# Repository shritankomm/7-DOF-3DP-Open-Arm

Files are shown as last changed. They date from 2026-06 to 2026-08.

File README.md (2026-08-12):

# 7-DOF Open Source 3D Printed Humanoid Arms

An open-source, fully 3D-printable 7-DOF pair of humanoid robotic arms designed as an accessible research platform. Built with high-torque Feetech serial bus servos and a Raspberry Pi 4, it supports ROS2 for motion planning/simulation, VR teleoperation for intuitive control, and autonomous/agentic operation via an onboard camera. With all CAD files, BOM, and software fully open source, anyone can build and expand on it for under $800.



---

## Inspiration
- I made this project because I find interest in is human-related robotics. The idea of being able to create some kind of device that can help or mimic a human's movement is a very cool thing, as human mechanics are very intricate. That's why I took the time to create as accurate a replica of the humans arms to make it work as well as possible. In the past, I have made foot prosthetics and other medical device prototypes, and this felt like a great next step. I also made this as an act to make a low-cost research tool for people to use, and as an ability for others and me to begin learning more advanced robotics. I'm exploring ROS, OpenCV, and other things that can be integrated with this project, and I feel this is the best way for people to learn things like this. I will document this journey and open-source it so others can follow and build upon the project, doing bigger, better, and more impressive things than I am with this project. I aim to inspire people to do more human-centered robotics, as it is the future. I have plans for more humanoid robot projects (a pair of legs, for example) and will document them on GitHub and make them open source so everyone can learn and grow as engineers.

---

## Features of the Project

- 7 Degrees of Freedom - full human-like range of motion across the shoulder, elbow, and wrist
- High-torque serial bus servos - 30 kgcm at most joints, 50kgcm at the shoulder
- Fully 3D printable - all structural components printed in PETG at high infill, no custom machined parts required
- ROS2 integration - built for compatibility with the broader robotics software ecosystem
- Advanced simulation using Gazebo 
- VR teleoperation - control the arm intuitively through a VR headset
- Autonomous and agentic control - onboard Raspberry Pi 4 and camera enable independent perception and decision-making
- Under $800 - accessible to students, researchers, and makers without big budgets

---

## Hardware

# Bill of Materials

| # | Part Name | Link | Source | Qty | Unit Price | Extended Price | Notes | Where It's Needed |
|---|---|---|---|-----|---|---|---|---|
| 1 | 1 KG PETG filament roll | [Link](https://www.amazon.com/gp/product/B0DJS3PJVX) | Amazon | 2 | $15.00 | $30.00 | | Needed to print out all the parts |
| 2 | STS3215 Servo (12V 30KG) | [Link](https://www.amazon.com/gp/product/B0FLPQQ4FR) | Amazon | 14 | $24.00 | $336.00 | | Main actuators used at all joints except the top shoulder roll joint |
| 3 | Serial Bus Servo Driver Board | [Link](https://www.amazon.com/gp/product/B0DK79JNNK) | Amazon | 2 | $11.00 | $22.00 | | Servo driver, supplies power to the arm and connects the Pi to send movement commands to the servos |
| 4 | Raspberry Pi 4 | [Link](https://www.amazon.com/gp/product/B0CK2FCG1K) | Amazon | 1 | $100.00 | $100.00 | | Microcontroller of the build, runs ROS and other programs |
| 5 | 12V 10A power supply | [Link](https://www.amazon.com/gp/product/B07MXXXBV8) | Amazon | 1 | $23.00 | $23.00 | | Connects to the wall and supplies power to the build |
| 6 | M3 heat set inserts | [Link](https://www.amazon.com/gp/product/B0DMNWZ15X) | Amazon | 1 | $7.00 | $7.00 | Kit includes both screws and inserts; same price if bought separately | Inserts go into 3D prints to strengthen threads; screws fasten components together |
| 7 | Logitech C270 Webcam | [Link](https://www.amazon.com/gp/product/B004FHO5Y6) | Amazon | 1 | $18.00 | $18.00 | For vision | USB cam for vision capabilities, lets the Pi make decisions based on vision |
| 8 | 4040 extrusion, 800mm | [Link](https://www.amazon.com/dp/B09WCSX8H3) | Amazon | 1 | $27.00 | $27.00 | | Extrusion bar needed to keep the arms elevated, acts as middle support |
| 9 | STS3250M | [Link](https://www.aliexpress.us/item/3256811842648895.html) | AliExpress | 2 | $75.00 | $150.00 | For the shoulder roll DOF (doesn't account for tariffs) | Servos for the shoulder pitch joints, higher torque |
| 10 | 2x4, 60 inches | [Link](https://www.homedepot.com/p/ProWood-2-in-x-4-in-x-4-ft-2-Grade-Dimensional-Lumber-271736/300524962) | Home Depot | 1 | $5.00 | $5.00 | For the stand | For the stand |
| 11 | 3" wood screws | [Link](https://www.amazon.com/Wensilon-Screws-137pcs-lbs-Exterior-Resistant/dp/B0FCFFN4LB) | Amazon | 8 | $6.00 | $6.00 | For the stand | For the stand |

**Total (excluding shipping): $700.00**

Link to BOM Spreadsheet - https://docs.google.com/spreadsheets/d/1n2eNZaHsdRUR-5rRqqR8Au6a7Qyu3wT80XMrWUhEQkk/edit?usp=sharing

---

## Electrical

This is the preliminary wiring diagram for the project.



## Repository Structure

- CAD/          - CAD files (STL/STEP/Onshape Public Link), screenshots, Parts List, 3d print settings 
- software/     - Software + electrical diagram, firmware, and ROS2 control code
- docs/      - Build journal entries and progress updates/documentation
- BOM.md        - Full bill of materials with links and prices
- instructions.md - Build and assembly instructions 
- pictures.md - pictures of the fully assembled arm 
- README.md     - This file

---

## Build Instructions

Full step-by-step assembly instructions can be found in instructions.md. Follow along via the build journal in /DOCS to track design decisions and progress in the meantime. (coming soon)

---

## License
Hardware designs: CERN-OHL-S v2 (or CC BY 4.0)

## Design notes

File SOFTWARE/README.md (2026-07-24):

# Humanoid Arms — ROS 2 Control & Simulation Software

A **ROS 2 (Jazzy)** software stack for an open-source **7-DOF humanoid
arms**: robot description (URDF/meshes), MoveIt motion planning, RViz/Gazebo
simulation, and a set of Python tools for **kinesthetic capture, replay, hardware
control, and real-time bilateral teleoperation** of the physical arm.

This folder is a self-contained **ROS 2 workspace** built with `colcon` — it holds
two ROS 2 packages (`humanoid_arms` and `humanoid_arms_moveit_config`, each with a
standard `package.xml`). Clone it, build it, and run.

**CHECK FILE_TREE.md TO SEE WHERE FILES ARE
**
---

## Requirements

- **Ubuntu 24.04**
- **ROS 2 Jazzy**
- **Gazebo Harmonic** (for the physics sim; optional if you only want RViz + MoveIt)
- **Python 3** with the **Feetech servo SDK** (`scservo_sdk`) for any hardware scripts

---

## Packages

| Package | What it is |
|---|---|
| `humanoid_arms` | Robot description (URDF + STL meshes), Gazebo launch, and all hardware/teleop Python scripts (`scripts/`). |
| `humanoid_arms_moveit_config` | MoveIt configuration (SRDF, kinematics, OMPL, controllers, joint limits) and the `demo.launch.py` that brings up RViz + MoveIt with mock controllers. |

> **Two URDFs, by design.** Gazebo uses `humanoid_arms/urdf/humanoid_arms_final.urdf`
> (with the Gazebo control plugin); MoveIt uses
> `humanoid_arms_moveit_config/config/humanoid_arms.urdf` (with the mock-components
> plugin). They describe the same robot but carry different `<plugin>` blocks.

---

## Build

```bash
# from the workspace root (this folder)
rosdep install --from-paths src -y --ignore-src     # install ROS dependencies
colcon build
source install/setup.bash
```

The Feetech SDK is a **pip** package, not a ROS one, so install it separately:

```bash
pip install feetech-servo-sdk        # provides `scservo_sdk`
```

---

## Wayland workaround (important for GUIs)

On Wayland, RViz and Gazebo can crash or render black. Export these **before any
GUI launch** (put them in your shell profile or prefix each launch):

```bash
export QT_QPA_PLATFORM=xcb
export LIBGL_ALWAYS_SOFTWARE=true
```

---

## Run the simulation

```bash
ros2 launch humanoid_arms_moveit_config demo.launch.py
```

This brings up RViz with the MoveIt MotionPlanning panel. Use **Plan & Execute**
(you must Execute, not just Plan) to pose the arm. The transparent/ghost arm is the
real robot state; the solid arm is the planning goal.

---

## Capture & replay (simulation)

Pose the arm in RViz, then:

```bash
# in the scripts/ directory, with the sim running
python3 capture_keyframes.py left        # ENTER snapshots each pose; s save, q quit
python3 replay_keyframes.py FILE.json --dt 1.5
```

---

## Hardware bring-up

The physical arm uses **Feetech STS3215/STS3250** servos on a TTL bus via a
Waveshare adapter (default `/dev/ttyACM0` @ 1 Mbaud) with a separate 12 V supply.

**Serial port permissions:** add your user to the `dialout` group once
(`sudo usermod -aG dialout $USER`, then log out/in), or per-session
`sudo chmod a+rw /dev/ttyACM0`.

### 1. Assign servo IDs
Left arm = IDs 2–8, left claw = 9, right arm = 10–16, right claw = 17.
```bash
python3 assign_ids_right_and_claws.py    # one fresh (ID 1) servo at a time
python3 ping_all_ids.py                  # confirm 2–17 respond
```

### 2. Calibrate
`servo_calibration.json` and `mirror_calibration.json` **in this repo are the
author's calibration** for a specific physical arm. **You must recalibrate for your
own hardware** — the zero ticks and signs will not match your build.

```bash
python3 capture_zero.py        # record each joint's zero tick (arm at zero pose)
python3 sign_calibrate.py      # find each joint's sign
python3 rezero_servo.py <id>   # re-center a servo to mid-range (fixes tick wraparound)
```

### 3. Drive the arm from captured motion
```bash
python3 replay_hardware.py FILE.json     # keyframes -> servo ticks
python3 teleop_record.py                 # go limp, record motion by hand (50 Hz)
python3 teleop_replay.py FILE.json       # stream a recording back onto the servos
```

---

## Real-time bilateral teleoperation

Move the **left** arm by hand (limp) and the **right** arm mirrors it live.

```bash
# 1. discover the reference pose + per-joint mirror signs (one time, watch the arm)
python3 mirror_calibrate.py              # writes mirror_calibration.json (8 pairs)

# 2. real-time mirror
python3 teleop_mirror.py                 # left limp -> right follows, incl. grippers
```

Just the grippers, in isolation:
```bash
python3 gripper_mirror.py
```

**How the mirror works.** Both arms use identical direct-drive servos, so mirroring
is done in raw tick space: `R = R0 + sign*(L - L0)`. `L0/R0` are the ticks at a
shared reference pose; `sign` (±1) encodes which joints are physically mirrored and
is found empirically during calibration. The teleop unwraps the 0–4095 tick seam so
yaw joints don't fling a full turn, and applies EMA smoothing + a per-loop slew
limit for safety.

---

## Script reference

All scripts live in `src/humanoid_arms/scripts/`. Sim scripts need `demo.launch.py`
running; hardware scripts need the servo bus powered and readable on `/dev/ttyACM0`.

**Servo bus setup**
| Script | What it does |
|---|---|
| `assign_servo_ids.py` | Assign IDs 2–8 to fresh servos (left arm), one at a time. |
| `assign_ids_right_and_claws.py` | Assign IDs 9–17 (left claw, right arm, right claw). |
| `ping_all_ids.py` | Ping the expected IDs and report which servos respond. |
| `map_servos.py` | Wiggle each servo to discover which one drives which joint. |

**Calibration**
| Script | What it does |
|---|---|
| `capture_zero.py` | Read-only: record each joint's zero tick with the arm at its URDF-zero pose. |
| `sign_calibrate.py` | Sim-vs-hardware jog to find each joint's ±1 sign. |
| `rezero_servo.py <id>` | Re-center any servo to mid-range and auto-update the calibration files (fixes tick-wraparound). |
| `rezero_elbow.py` | Elbow-only re-center — **superseded by `rezero_servo.py 5`** (kept for reference). |
| `read_live.py <id>` | Torque-off live tick readout — move a joint by hand and watch its ticks. |

**Simulation / IK**
| Script | What it does |
|---|---|
| `ik_trajectory.py` | FK-anchored straight-line Cartesian sweep; solves IK per waypoint, writes a CSV. |
| `ik_explorer.py` | Builds RobotModel from URDF+SRDF; solves single-point and straight-line Cartesian IK offline. |
| `pose_and_capture.py` | Interactive-marker poser + capture — **superseded** by MoveIt Plan&Execute + `capture_keyframes.py`. |

**Keyframe capture & replay**
| Script | What it does |
|---|---|
| `capture_keyframes.py` | Snapshot the current joint states as keyframes (sim). |
| `replay_keyframes.py` | Replay a keyframe JSON through the controllers (sim). |
| `replay_hardware.py` | Replay a keyframe JSON on the physical servos (rad→tick). |
| `hw_goto.py` | Drive the real arm to one pose/keyframe and optionally mirror it in the sim, to validate calibration. |

**Kinesthetic teleop (record by hand → replay)**
| Script | What it does |
|---|---|
| `teleop_record.py` | Go limp, record dense motion (50 Hz) as you move the arm by hand. |
| `teleop_replay.py` | Stream a teleop recording back onto the servos. |

**Real-time bilateral (mirror) teleop**
| Script | What it does |
|---|---|
| `mirror_calibrate.py` | Discover the reference pose + per-joint mirror signs → writes `mirror_calibration.json`. |
| `teleop_mirror.py` | Real-time: left arm limp leads, right arm mirrors it (all 7 joints + gripper). |
| `gripper_mirror.py` | Standalone gripper-only mirror (left claw → right claw). |

**Basic bring-up tests**
| Script | What it does |
|---|---|
| `test_wiggle.py` | Gently wiggle a single servo around its current position. |
| `test_wiggle_dual.py` | Sync-wiggle two servos at once (group sync-write demo). |

---

## Safety notes

- **Read servo positions before enabling torque** so the arm doesn't snap to a stale
  command.
- Generated IK angles can exceed a servo's physical range — sanity-check before
  driving hardware. The scripts clamp to each joint's `[tick_min, tick_max]`.
- The arm goes **limp** when torque is released (kinesthetic capture, teleop leader) —
  support it so it doesn't fall.
- Confirm the servo bus responds (`ping_all_ids.py`) with 12 V on *before* recording;
  a powered-off bus silently logs frozen fallback values.



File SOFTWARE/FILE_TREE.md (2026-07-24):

# File Tree — `SOFTWARE/`

A guide to what's in this folder and where to find things. 

```
SOFTWARE/
├── README.md                     # start here: requirements, build, run, script reference
├── .gitignore                    # keeps build/ install/ log/, caches, recordings out of git
└── src/                          # colcon looks here for ROS 2 packages
    │
    ├── humanoid_arms/                     # robot description + all Python tooling
    │   ├── package.xml                    # ROS 2 package manifest (name, deps, license)
    │   ├── CMakeLists.txt                 # build/install rules
    │   │
    │   ├── config/
    │   │   └── controllers.yaml           # ros2_control controller definitions
    │   │
    │   ├── launch/
    │   │   ├── display.launch.py          # robot in RViz (no physics)
    │   │   └── gazebo.launch.py           # robot in Gazebo (physics sim)
    │   │
    │   ├── urdf/                          # robot geometry/kinematics description
    │   │   ├── humanoid_arms_final.urdf   # ★ the Gazebo robot model (source of truth)
    │   │   ├── humanoid_arms_collision.urdf     # variant w/ collision geometry
    │   │   ├── humanoid_arms_fixed.urdf         # intermediate build step
    │   │   ├── humanoid_arms_ros2_control.urdf  # intermediate build step
    │   │   ├── add_gazebo_plugin.py       # URDF build helper: injects the Gazebo plugin
    │   │   ├── add_ros2_control.py        # URDF build helper: injects ros2_control block
    │   │   └── add_collisions.py          # URDF build helper: adds collision meshes
    │   │
    │   ├── meshes/                        # 56 .stl CAD meshes the URDF references
    │   │                                  #   (chest_plate, shoulder/elbow/wrist parts,
    │   │                                  #    servo bodies, claw arms, frame extrusions)
    │   │
    │   └── scripts/                       # Python tools (see README "Script reference")
    │       │  ── servo bus setup ──
    │       ├── assign_servo_ids.py        # assign IDs 2–8 (left arm)
    │       ├── assign_ids_right_and_claws.py  # assign IDs 9–17 (claws + right arm)
    │       ├── ping_all_ids.py            # check which servos respond
    │       ├── map_servos.py              # discover which servo drives which joint
    │       │  ── calibration ──
    │       ├── capture_zero.py            # record each joint's zero tick (read-only)
    │       ├── sign_calibrate.py          # find each joint's ±1 sign
    │       ├── rezero_servo.py            # re-center a servo to mid-range (fixes wraparound)
    │       ├── rezero_elbow.py            # elbow-only re-center (superseded by rezero_servo)
    │       ├── read_live.py               # live tick readout, joint moved by hand
    │       ├── servo_calibration.json     # ⚙ per-joint hw calibration (RECALIBRATE for your arm)
    │       ├── mirror_calibration.json    # ⚙ left↔right mirror reference + signs
    │       │  ── simulation / IK ──
    │       ├── ik_trajectory.py           # straight-line Cartesian IK sweep → CSV
    │       ├── ik_explorer.py             # offline IK from URDF+SRDF
    │       ├── pose_and_capture.py        # marker poser (superseded by MoveIt + capture)
    │       │  ── keyframe capture / replay ──
    │       ├── capture_keyframes.py       # snapshot joint poses as keyframes (sim)
    │       ├── replay_keyframes.py        # replay keyframes through controllers (sim)
    │       ├── replay_hardware.py         # replay keyframes on the real servos
    │       ├── hw_goto.py                 # drive real arm to one pose; validate calibration
    │       │  ── kinesthetic teleop ──
    │       ├── teleop_record.py           # go limp, record motion by hand at 50 Hz
    │       ├── teleop_replay.py           # stream a recording back onto the servos
    │       │  ── real-time bilateral (mirror) teleop ──
    │       ├── mirror_calibrate.py        # find reference + mirror signs → mirror_calibration.json
    │       ├── teleop_mirror.py           # ★ left arm limp → right arm mirrors live (+ gripper)
    │       ├── gripper_mirror.py          # standalone gripper-only mirror
    │       │  ── basic bring-up tests ──
    │       ├── test_wiggle.py             # wiggle one servo around its current position
    │       └── test_wiggle_dual.py        # sync-wiggle two servos at once
    │
    └── humanoid_arms_moveit_config/       # MoveIt motion-planning configuration
        ├── package.xml                    # ROS 2 package manifest
        ├── CMakeLists.txt                 # build/install rules
        ├── .setup_assistant               # lets MoveIt Setup Assistant re-open/regenerate this
        │
        ├── config/
        │   ├── humanoid_arms.urdf         # robot model MoveIt uses (mock-controllers variant)
        │   ├── humanoid_arms.srdf         # semantic model: groups, tips, disabled collisions
        │   ├── kinematics.yaml            # IK solver (pick_ik) settings per arm
        │   ├── joint_limits.yaml          # velocity/acceleration limits
        │   ├── ompl_planning.yaml         # OMPL planner config
        │   ├── moveit_controllers.yaml    # maps MoveIt to the ros2_control controllers
        │   ├── ros2_controllers.yaml      # controller manager + controller definitions
        │   ├── pilz_cartesian_limits.yaml # Pilz planner limits
        │   └── moveit.rviz                # saved RViz layout (MotionPlanning panel)
        │
        └── launch/
            ├── demo.launch.py             # ★ full bring-up: MoveIt + RViz + mock controllers
            ├── move_group.launch.py       # the MoveIt planning node
            ├── moveit_rviz.launch.py      # RViz with the MotionPlanning plugin
            ├── rsp.launch.py              # robot_state_publisher
            ├── spawn_controllers.launch.py     # start the ros2_control controllers
            ├── static_virtual_joint_tfs.launch.py  # world→base static TF
            ├── setup_assistant.launch.py  # re-open the MoveIt Setup Assistant
            └── warehouse_db.launch.py     # (optional) motion warehouse database
```

## Where do I go for guide
- **Just run the sim** → `README.md` → *Run the simulation* (`demo.launch.py`)
- **Understand the robot** → `src/humanoid_arms/urdf/humanoid_arms_final.urdf` + `meshes/`
- **Capture & replay a pose** → `scripts/capture_keyframes.py`, `scripts/replay_keyframes.py`
- **Drive the real arm** → `README.md` → *Hardware bring-up* + `scripts/` (assign IDs → calibrate → replay)
- **Bilateral teleop** → `scripts/mirror_calibrate.py` then `scripts/teleop_mirror.py`

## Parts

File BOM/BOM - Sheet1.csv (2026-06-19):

## | Part Name | Link | Quantity | Unit Price | Extended Price | Notes | where it is needed
1 | 1 KG PETG filament roll | link | 2 | $15.00 | $30.00 |  | Needed to print out all the parts
2 | STS3215 Servo (12V 30KG) | link | 14 | $24.00 | $336.00 |  | the main actuators that will be used at all joints except for the top shoulder roll joint
3 | Serial Bus Servo Driver Board | link | 2 | $11.00 | $22.00 |  | the servo driver, will be where power is supplied to the arm and where the Pi is connected to give movement commands to the servos
4 | Rasberry Pi 4 | link | 1 | $100.00 | $100.00 |  | the microcontroller of the build will be used to run ROS and run programs on the build
5 | 12V 10A power supply | link | 1 | $23.00 | $23.00 |  | power supply that will connect to the wall and be used to supply power to the build
6 | m3 heat set inserts | link | 1 | $7.00 | $7.00 | this kit has both screws and inserts but if you were to buy them seperatly it would be the same price | the choice of heatset inserts, which go into the 3d prints to strengthen the threads, and the screws which will be used to fasten components together
7 | Logitech C270 Webcam | link | 1 | $18.00 | $18.00 | for vision | usb cam used for vision capabilities for the project, allows the rasberry pi to make decisions based on vision
8 | 4040 Corner brackets + Tnuts | link | 1 | $20.00 | $20.00 |  | the main piece at the bottom of the extrusion which will bolt to the table and hold the arm in place
9 | 4040 extrusion 800mm | link | 1 | $27.00 | $27.00 |  | the extrusion bar needed to keep the arms in the air, act as. middle support
10 | STSS3250M (doesnt account for the tarrifs) | link | 2 | $75.00 | $150.00 | for the shoulder roll DOF (doesnt account for the tarrifs) | the servos needed for the shoulder pitch joints, higher torque
11 | 5264 connector 3 pin extended wires | link | 1 | $7.00 | $7.00 |  | wire extensions for the motors to allow for proper daisy chaining with the motors so they can all be connected in an open loop.
12 |  |  |  |  | $0.00
 |  |  | ` |  | $740.00 | total

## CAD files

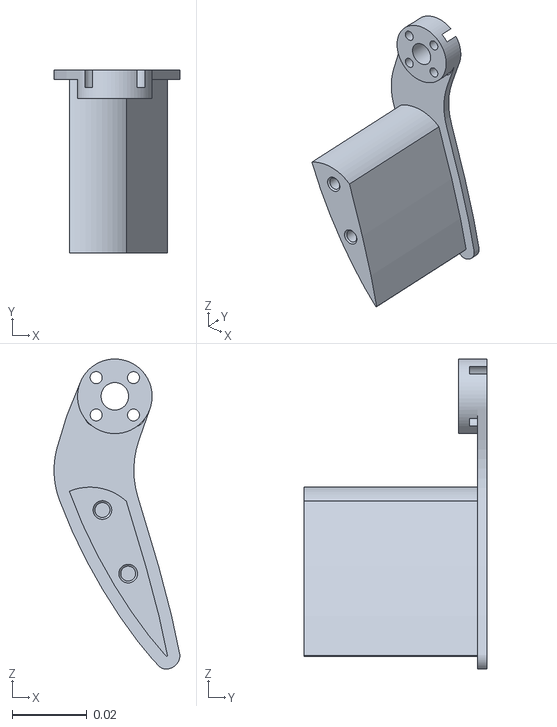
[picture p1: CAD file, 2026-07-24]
SOFTWARE/src/humanoid_arms/meshes/bottom_stationary_claw_arm.stl
0.0337 x 0.0491 x 0.0831

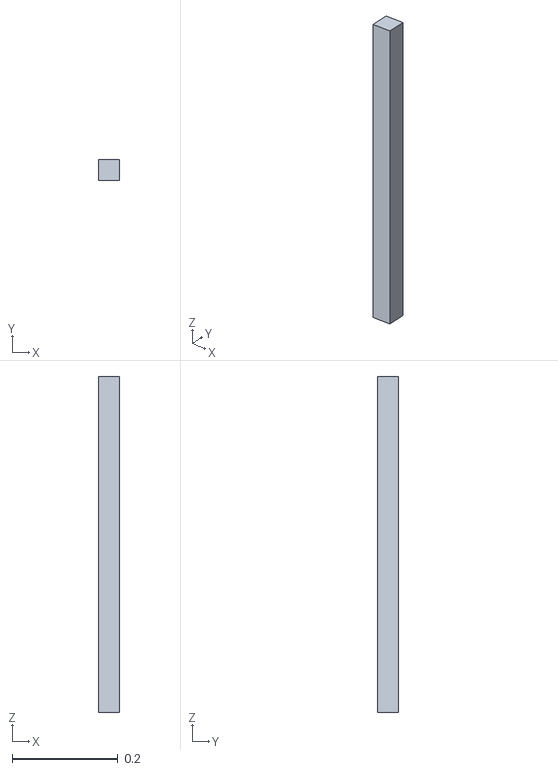
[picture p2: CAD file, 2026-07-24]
SOFTWARE/src/humanoid_arms/meshes/_4040_extrusion.stl
0.04 x 0.04 x 0.635

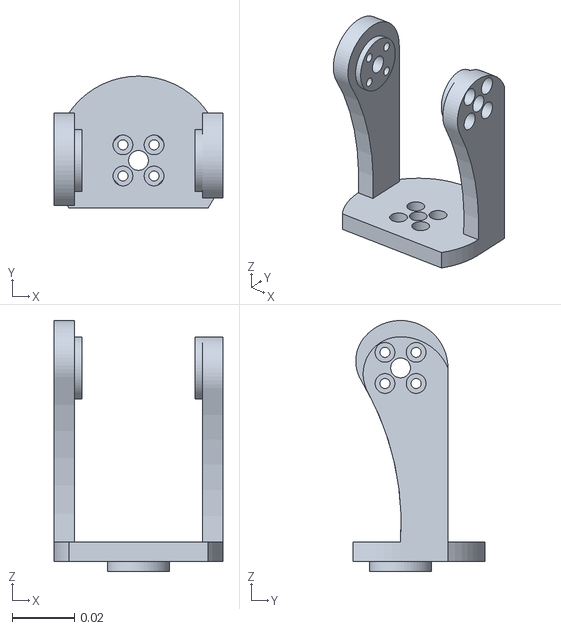
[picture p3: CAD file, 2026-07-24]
SOFTWARE/src/humanoid_arms/meshes/Part_42.stl
0.0542 x 0.0423 x 0.0806

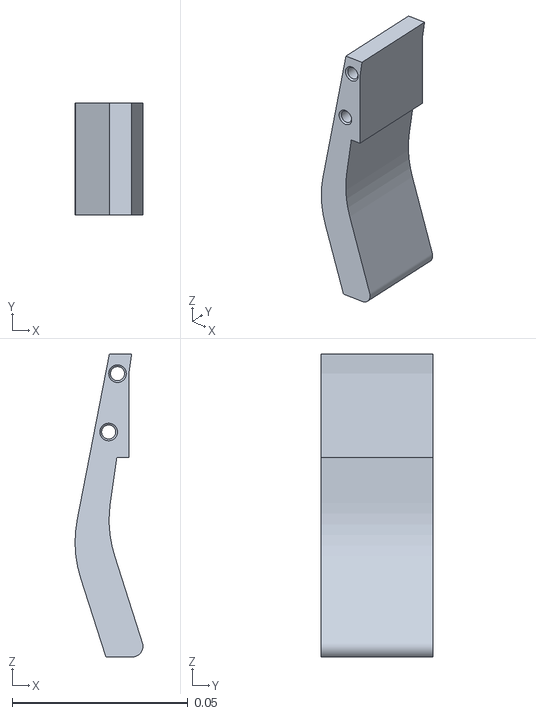
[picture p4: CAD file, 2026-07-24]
SOFTWARE/src/humanoid_arms/meshes/Part_54.stl
0.0193 x 0.0318 x 0.0863

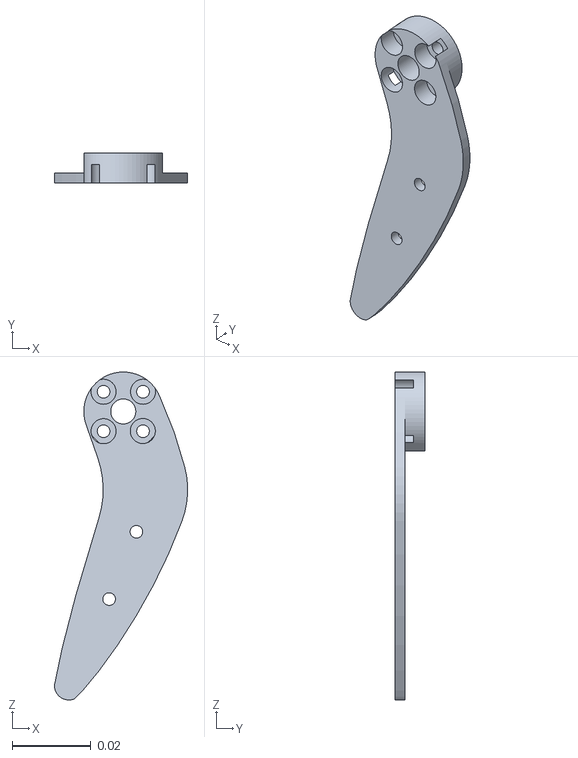
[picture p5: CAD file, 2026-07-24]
SOFTWARE/src/humanoid_arms/meshes/Part_53.stl
0.0337 x 0.00762 x 0.0831

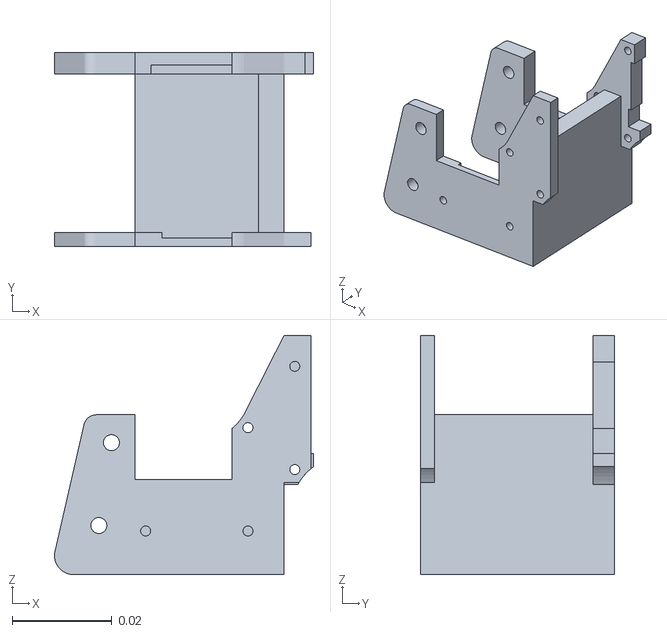
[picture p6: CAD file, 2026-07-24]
SOFTWARE/src/humanoid_arms/meshes/Part_51.stl
0.0519 x 0.0389 x 0.0479

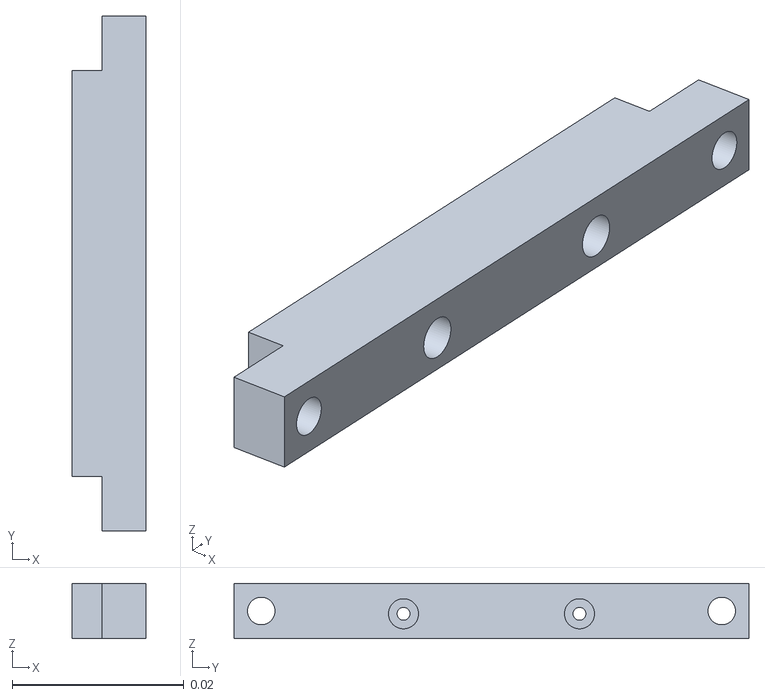
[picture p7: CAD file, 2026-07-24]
SOFTWARE/src/humanoid_arms/meshes/shoulder_pitch_motor_back_plate.stl
0.00858 x 0.06 x 0.00645

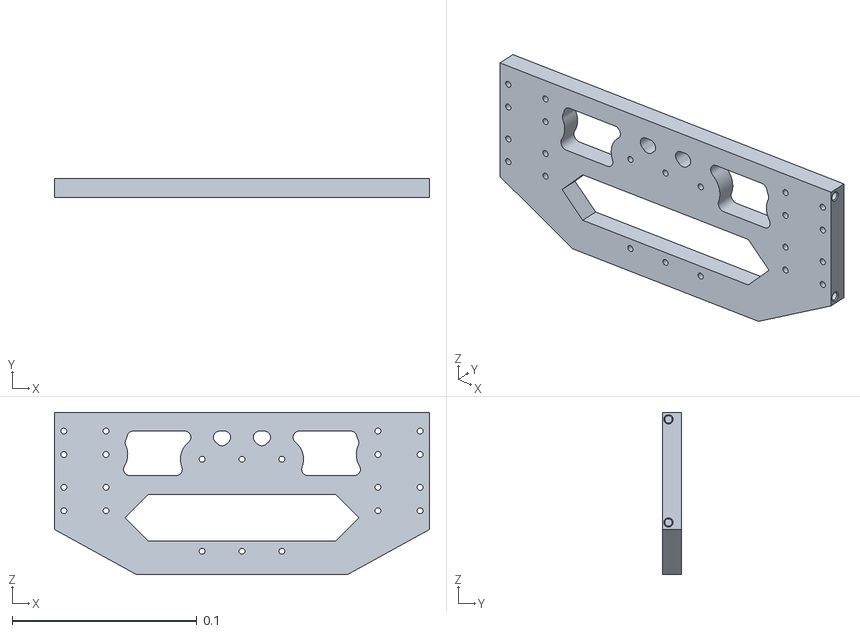
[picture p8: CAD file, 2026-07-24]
SOFTWARE/src/humanoid_arms/meshes/chest_plate_1.stl
0.203 x 0.0102 x 0.088

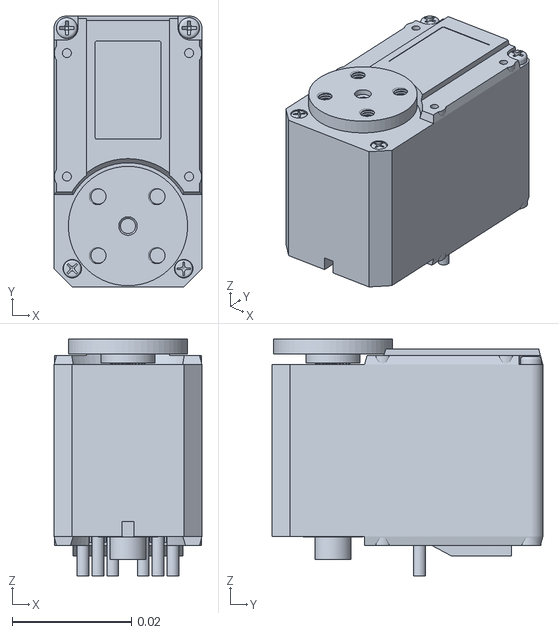
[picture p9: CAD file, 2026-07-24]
SOFTWARE/src/humanoid_arms/meshes/Composant3_3.stl
0.0248 x 0.0454 x 0.0397

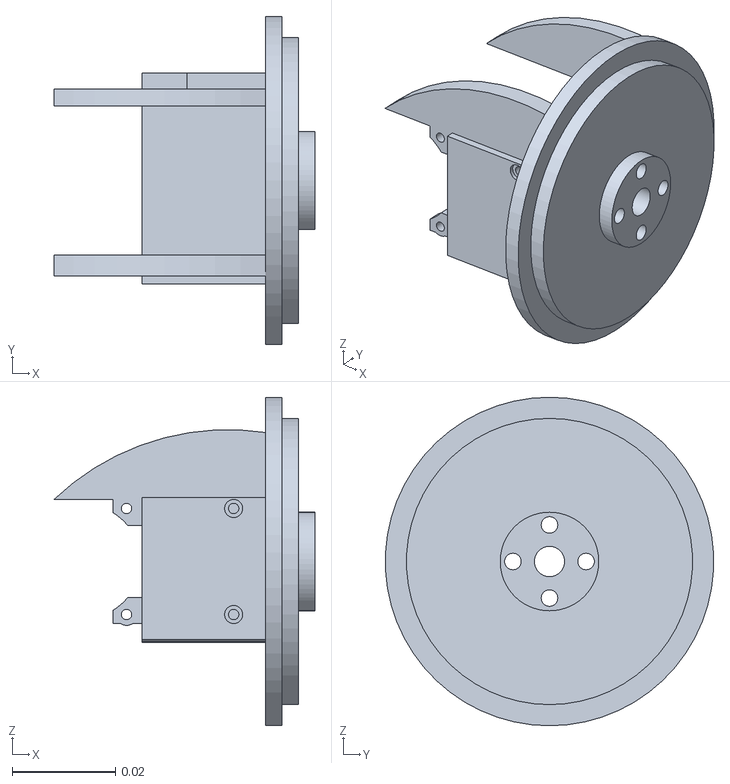
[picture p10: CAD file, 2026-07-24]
SOFTWARE/src/humanoid_arms/meshes/shoulder_motor_holder.stl
0.0505 x 0.0634 x 0.0635

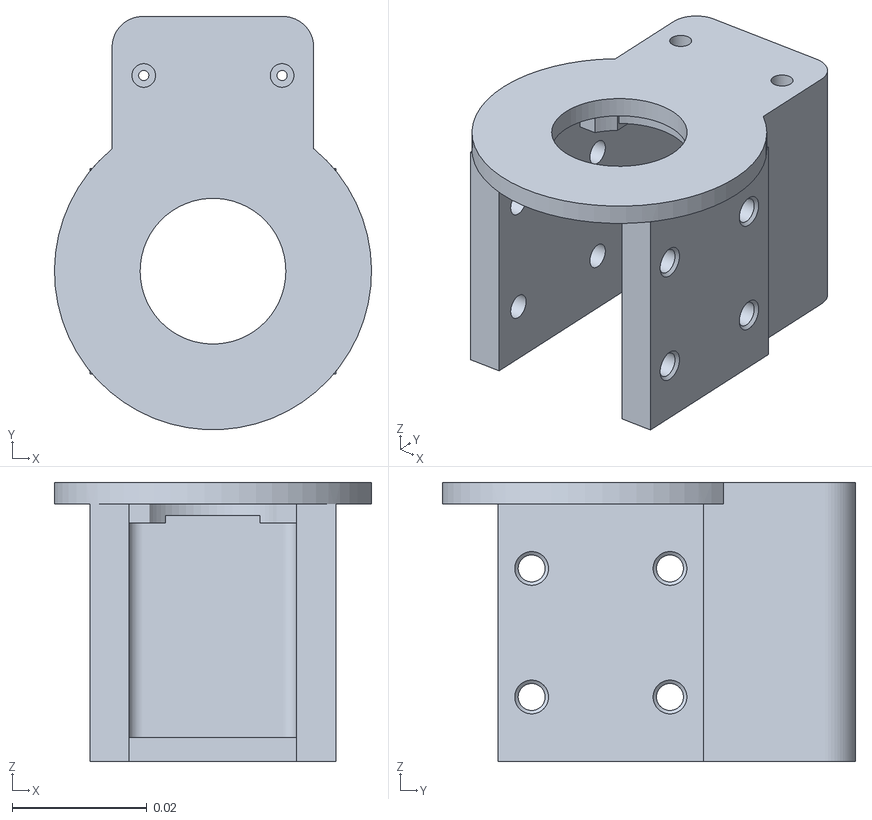
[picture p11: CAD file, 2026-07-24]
SOFTWARE/src/humanoid_arms/meshes/Part_43.stl
0.047 x 0.0612 x 0.0414

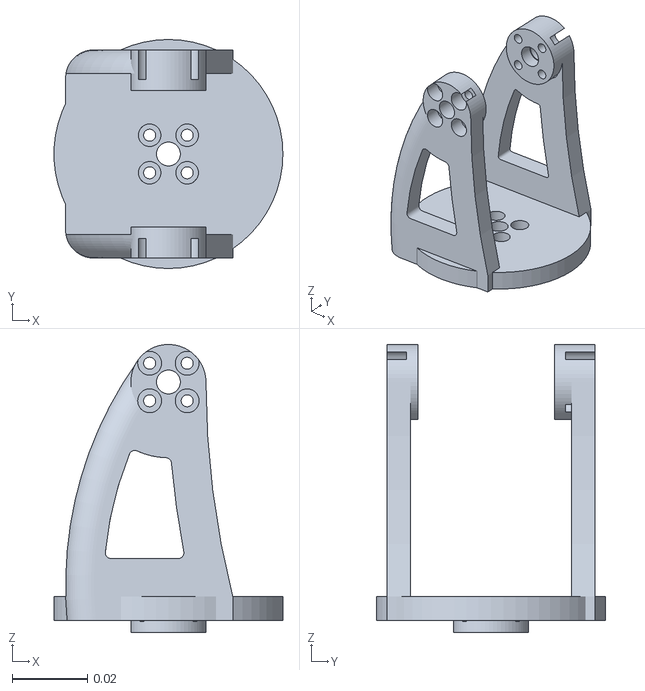
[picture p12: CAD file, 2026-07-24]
SOFTWARE/src/humanoid_arms/meshes/shoulder_roll_part.stl
0.0609 x 0.061 x 0.0767

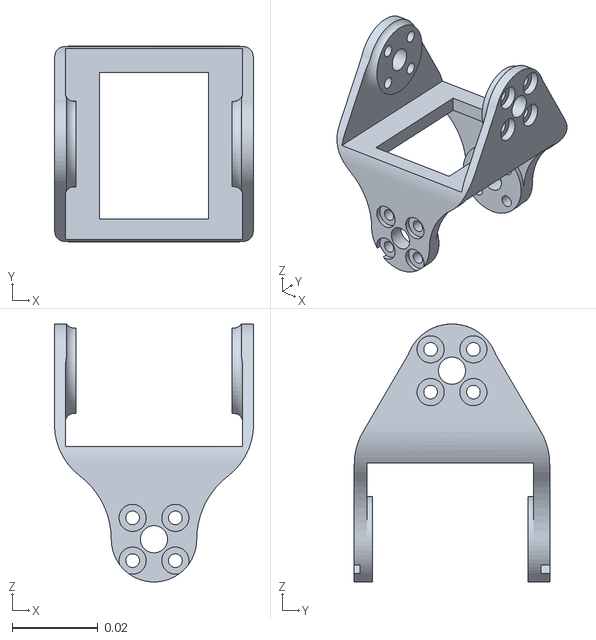
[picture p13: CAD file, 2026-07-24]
SOFTWARE/src/humanoid_arms/meshes/wrist_pitch_to_roll_connector.stl
0.0466 x 0.0457 x 0.0603

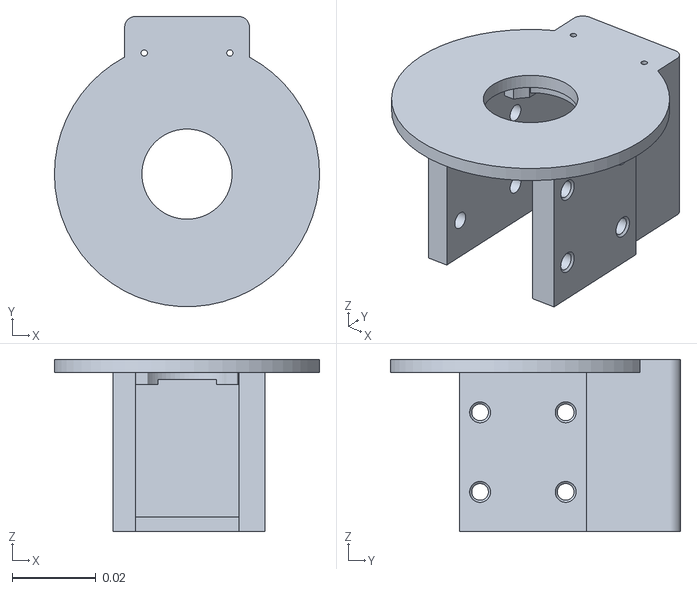
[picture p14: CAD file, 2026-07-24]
SOFTWARE/src/humanoid_arms/meshes/arm_yaw_connector.stl
0.0635 x 0.0694 x 0.0413

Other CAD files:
SOFTWARE/src/humanoid_arms/meshes/elbow_pitch_part.stl
SOFTWARE/src/humanoid_arms/meshes/chest_plate.stl
SOFTWARE/src/humanoid_arms/meshes/top_non_stationary_claw_arm.stl
SOFTWARE/src/humanoid_arms/meshes/Part_56.stl
SOFTWARE/src/humanoid_arms/meshes/Composant3_6.stl
SOFTWARE/src/humanoid_arms/meshes/Composant3_7.stl
SOFTWARE/src/humanoid_arms/meshes/Part_31.stl
SOFTWARE/src/humanoid_arms/meshes/Part_35.stl
SOFTWARE/src/humanoid_arms/meshes/Part_37.stl
SOFTWARE/src/humanoid_arms/meshes/Part_38.stl
SOFTWARE/src/humanoid_arms/meshes/Part_40.stl
SOFTWARE/src/humanoid_arms/meshes/Part_41.stl
SOFTWARE/src/humanoid_arms/meshes/Part_45.stl
SOFTWARE/src/humanoid_arms/meshes/Part_47.stl
SOFTWARE/src/humanoid_arms/meshes/Part_48.stl
SOFTWARE/src/humanoid_arms/meshes/Part_50.stl
SOFTWARE/src/humanoid_arms/meshes/Part_55.stl
SOFTWARE/src/humanoid_arms/meshes/R_offset_shoulder_motor_holder.stl
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

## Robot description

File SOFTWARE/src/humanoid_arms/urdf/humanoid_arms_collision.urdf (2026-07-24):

<?xml version='1.0' encoding='utf-8'?>
<robot name="humanoid_arms">
  <link name="4040_extrusion">
    <inertial>
      <mass value="2.87528" />
      <origin xyz="0 8.55321e-19 0.3175" rpy="0 -0 0" />
      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
    </inertial>
    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
  </link>
  <link name="arm_yaw_connector">
    <inertial>
      <mass value="0.0400862" />
      <origin xyz="0.0108869 -0.0242783 0.0224562" rpy="0 -0 0" />
      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
    </inertial>
    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
  </link>
  <link name="bicep_screw_bar">
    <inertial>
      <mass value="0.0415979" />
      <origin xyz="-0.004445 0.0115793 -0.0699535" rpy="0 -0 0" />
      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
    </inertial>
    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
  </link>
  <link name="bicep_screw_bar_1">
    <inertial>
      <mass value="0.0416004" />
      <origin xyz="0.004445 0.0115799 -0.0699366" rpy="0 -0 0" />
      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
    </inertial>
    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
  </link>
  <link name="bottom_stationary_claw_arm">
    <inertial>
      <mass value="0.0304237" />
      <origin xyz="0.00453712 0.0276565 -0.00855211" rpy="0 -0 0" />
      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
    </inertial>
    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
  </link>
  <link name="chest_plate">
    <inertial>
      <mass value="0.158882" />
      <origin xyz="-1.47634e-17 -0.00509001 -0.0153834" rpy="0 -0 0" />
      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
    </inertial>
    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
  </link>
  <link name="chest_plate_1">
    <inertial>
      <mass value="0.158882" />
      <origin xyz="3.66326e-17 0.00509001 -0.0153834" rpy="0 -0 0" />
      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
    </inertial>
    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
  </link>
  <link name="chest_plate_holder">
    <inertial>
      <mass value="0.0611626" />
      <origin xyz="9.84487e-18 0.03 1.11022e-16" rpy="0 -0 0" />
      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
    </inertial>
    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
  </link>
  <link name="chest_plate_holder_1">
    <inertial>
      <mass value="0.0611626" />
      <origin xyz="7.38006e-18 2.57088e-11 -0.0127" rpy="0 -0 0" />
      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
    </inertial>
    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
  </link>
  <link name="composant3">
    <inertial>
      <mass value="0.0549949" />
      <origin xyz="-7.78933e-09 0.0184791 -0.0128065" rpy="0 -0 0" />
      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
    </inertial>
    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
  </link>
  <link name="composant3_1">
    <inertial>
      <mass value="0.0549949" />
      <origin xyz="0.0199935 -0.0161209 -0.01025" rpy="0 -0 0" />
      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
    </inertial>
    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
  </link>
  <link name="composant3_2">
    <inertial>
      <mass value="0.0549949" />
      <origin xyz="0.0156791 0.01025 -0.0161935" rpy="0 -0 0" />
      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
    </inertial>
    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
  </link>
  <link name="composant3_3">
    <inertial>
      <mass value="0.053985" />
      <origin xyz="1.1421e-09 0.013046 -0.0182339" rpy="0 -0 0" />
      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
    </inertial>
    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
  </link>
  <link name="composant3_4">
    <inertial>
      <mass value="0.0549949" />
      <origin xyz="0.01025 0.0156791 -0.0161935" rpy="0 -0 0" />
      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
    </inertial>
    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
  </link>
  <link name="composant3_5">
    <inertial>
      <mass value="0.0549949" />
      <origin xyz="0.0156791 0.01025 0.00450648" rpy="0 -0 0" />
      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
    </inertial>
    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
  </link>
  <link name="composant3_6">
    <inertial>
      <mass value="0.053985" />
      <origin xyz="1.1421e-09 0.013046 -0.0182339" rpy="0 -0 0" />
      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
    </inertial>
    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
  </link>
  <link name="composant3_7">
    <inertial>
      <mass value="0.053985" />
      <origin xyz="-0.0154339 0.01025 -0.015954" rpy="0 -0 0" />
      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
    </inertial>
    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
  </link>
  <link name="elbow_pitch_part">
    <inertial>
      <mass value="0.038435" />
      <origin xyz="-0.0173025 0.00423555 -0.035971" rpy="0 -0 0" />
      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
    </inertial>
    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
  </link>
  <link name="elbow_to_bicep_motor_connector">
    <inertial>
      <mass value="0.0273027" />
      <origin xyz="0.0185431 0.0102296 -0.0068729" rpy="0 -0 0" />
      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
    </inertial>
    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
  </link>
  <link name="forearm_screw_bar">
    <inertial>
      <mass value="0.0349863" />
      <origin xyz="0.004445 0.01025 -0.0374007" rpy="0 -0 0" />
      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
    </inertial>
    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
  </link>
  <link name="forearm_screw_bar_1">
    <inertial>
      <mass value="0.0349863" />
      <origin xyz="-0.004445 0.01025 -0.037425" rpy="0 -0 0" />
      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
    </inertial>
    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
  </link>
  <link name="forearm_yaw_part">
    <inertial>
      <mass value="0.0352035" />
      <origin xyz="0.01023 -0.0224211 0.0205984" rpy="0 -0 0" />
      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
    </inertial>
    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
  </link>
  <link name="part_31">
    <inertial>
      <mass value="0.0748477" />
      <origin xyz="0.0152204 0.03 -0.0204798" rpy="0 -0 0" />
      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
    </inertial>
    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
  </link>
  <link name="part_35">
    <inertial>
      <mass value="0.0507257" />
      <origin xyz="0.00228689 -0.0167954 -0.0441378" rpy="0 -0 0" />
      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
    </inertial>
    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
  </link>
  <link name="part_37">
    <inertial>
      <mass value="0.0400862" />
      <origin xyz="0.00961314 -0.0242783 0.0224562" rpy="0 -0 0" />
      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
    </inertial>
    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
  </link>
  <link name="part_38">
    <inertial>
      <mass value="0.0273027" />
      <origin xyz="0.0178569 0.0102296 -0.0030729" rpy="0 -0 0" />
      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
    </inertial>
    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
  </link>
  <link name="part_40">
    <inertial>
      <mass value="0.0416004" />
      <origin xyz="-0.004445 0.0115799 -0.0699366" rpy="0 -0 0" />
      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
    </inertial>
    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
  </link>
  <link name="part_41">
    <inertial>
      <mass value="0.0415979" />
      <origin xyz="0.004445 0.0115793 -0.0699535" rpy="0 -0 0" />
      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
    </inertial>
    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
  </link>
  <link name="part_42">
    <inertial>
      <mass value="0.038435" />
      <origin xyz="-0.0190975 0.00423555 -0.035971" rpy="0 -0 0" />
      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
    </inertial>
    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
  </link>
  <link name="part_43">
    <inertial>
      <mass value="0.0352035" />
      <origin xyz="0.01027 -0.0224211 0.0205984" rpy="0 -0 0" />
      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
    </inertial>
    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
  </link>
  <link name="part_45">
    <inertial>
      <mass value="0.0152781" />
      <origin xyz="0.0179198 0.01025 -0.00112174" rpy="0 -0 0" />
      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
    </inertial>
    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
  </link>
  <link name="part_47">
    <inertial>
      <mass value="0.0349863" />
      <origin xyz="-0.004445 0.01025 -0.0564507" rpy="0 -0 0" />
      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
    </inertial>
    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
  </link>
  <link name="part_48">
    <inertial>
      <mass value="0.0349863" />
      <origin xyz="0.004445 0.01025 -0.056475" rpy="0 -0 0" />
      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
    </inertial>
    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
  </link>
  <link name="part_50">
    <inertial>
      <mass value="0.0168176" />
      <origin xyz="0.0181892 0.000612818 -0.0186515" rpy="0 -0 0" />
      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
    </inertial>
    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
  </link>
  <link name="part_51">
    <inertial>
      <mass value="0.0202264" />
      <origin xyz="0.0144941 0.017844 0.00564815" rpy="0 -0 0" />
      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
    </inertial>
    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
  </link>
  <link name="part_53">
    <inertial>
      <mass value="0.00569577" />
      <origin xyz="3.09435e-05 -0.00534853 -0.0235591" rpy="0 -0 0" />
      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
    </inertial>
    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
  </link>
  <link name="part_54">
    <inertial>
      <mass value="0.0334216" />
      <origin xyz="-0.000571143 -0.0159 -0.0256216" rpy="0 -0 0" />
      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
    </inertial>
    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
  </link>
  <link name="part_55">
    <inertial>
      <mass value="0.0304237" />
      <origin xyz="-0.00453712 0.0276565 -0.00855211" rpy="0 -0 0" />
      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
    </inertial>
    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
  </link>
  <link name="part_56">
    <inertial>
      <mass value="0.00369444" />
      <origin xyz="-0.0044473 0.01025 0.000337856" rpy="0 -0 0" />
      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
    </inertial>
    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
  </link>
  <link name="r_offset_shoulder_motor_holder">
    <inertial>
      <mass value="0.0354222" />
      <origin xyz="0.0119671 -0.000562638 0.000415977" rpy="0 -0 0" />
      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
    </inertial>
    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
  </link>
  <link name="root" />
  <link name="servo">
    <inertial>
      <mass value="0.0549949" />
      <origin xyz="0.0161209 0.01025 -0.0199935" rpy="0 -0 0" />
      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
    </inertial>
    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
  </link>
  <link name="servo_1">
    <inertial>
      <mass value="0.0549949" />
      <origin xyz="7.79543e-09 0.0184791 -0.0128065" rpy="0 -0 0" />
      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
    </inertial>
    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
  </link>
  <link name="servo_2">
    <inertial>
      <mass value="0.053985" />
      <origin xyz="0.0154339 0.01025 -0.015954" rpy="0 -0 0" />
      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
    </inertial>
    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
  </link>
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

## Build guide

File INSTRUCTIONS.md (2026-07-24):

# 7 DOF Humanoid Arm — Assembly Instructions

This guide covers the full build of the 7 DOF humanoid arm system, including the stand.

- **Section 1** — Full parts list
- **Section 2** — Assembly Instructions (step by step guide)

---

## Section 1 — Parts List

### Stand

| Part | Qty |
|---|---|
| 20 in 2x4 wood | 3 |
| 6 in 2x4 wood | 1 |
| 3 in #8 self tapping wood screws | 8 |
| 30 in 4040 aluminum extrusion | 1 |

### Arms (both arms) 

| Part | Qty |
|---|---|
| 3D printed parts | see print list |
| Feetech STS3250 servo | 2 |
| Feetech STS3215 servo | 14 |
| 1/16 M3 Washers | 4 |
| M3 heat set inserts | 50+ (as needed) |
| M3 x 16 mm socket head | 44 |
| M3 x 12 mm socket head | 48 |
| M3 x 8 mm socket head | 4 |
| M3 x 6 mm socket head | 8 |
| M3 x 6 mm motor screws | 120 |
| M2 x 5 mm self-tapping motor screws | 58 |

### Electronics

| Part | Qty |
|---|---|
| Waveshare Bus Servo Adapter board | 1 |
| 3 prong servo wires | 16 |
| 12 V 10 A power adapter | 1 |

---

## Section 2 — Assembly of Arms and Stand



### Before you start — heat set inserts + extra info/tips

- For any part with holes that are 0.157 in with a 0.2 in chamfer, press M3 heat set inserts into them using a soldering iron



- Any part with a hole that is .126 is a M3 screw pilot hole so those will connect to other componenets using m3 screws 

- Any part with .079 is a m2 screw pilot hole so those parts will connect to motors via self tapping screws

- Any screw that has the word Motor in it is a star head and is provided with the motors when purchased so dont use socket head screws for connecting parts to the servo horns.

---

### Step 1



Description: Slide the Chest Plate Holder onto the 4040 extrusion and connect the two chest plates to the holder by adding screws to the corresponding holes

Fasteners: M3 16mm (12x)

---

### Step 2



Description: Once the chest plates are connected, add in the Shoulder Pitch Motor holder by adding screws to the corresponding holes. Make sure to do it on the front, back, and sides.

Fasteners: M3 16mm (16x)

---

### Step 3



Description: Now slide the STS3250 servo (with horn) into the motor holder covering and and use m2 self tap screws to screw it into place. Then add on the shoulder roll motor holder and use m3 motor screws to attach it to the horn. 

Fasteners: M3 6mm motor screws (5x), M2 5mm self tapping screws (2x)

---

### Step 4



Description: Now add the arm yaw motor to the holder and connect the shoulder roll part to the servo horn, making sure to add a 1/16th washer in between the connection of the two parts to give a little gap and ease the friction. Then connect the motor to the part using M2 self-thread screws in the holes on the bottom of the arm yaw part.

Fasteners: M2 5mm self tapping screws (2x), M3 6mm motor screws (5x), 1/16 washer

---

### Step 5



Description: Now connect the Bicep bars to the Arm Yaw part using 12mm m3 screws, then, before adding in the elbow pitch motor holder, make sure to put the motor into the part and secure it using the m2 screws. Then, using 12mm m3 screws connect the part to the bottom of the bicep bars. 

Fasteners: M2 5mm self tapping screws (4x), M3 12mm (8x)

---

### Step 6



Description: Now add the forearm yaw motor to the holder and connect the elbow pitch part to the servo horn, making sure to add a 1/16th washer in between the connection of the two parts to give a little gap and ease the friction. Then connect the motor to the part using M2 self-thread screws in the holes on the bottom of the forearm yaw part.

Fasteners: M2 5mm self tapping screws (2x), M3 6mm motor screws (5x), 1/16 washer

---

### Step 7



Description: Now connect the forearm bars to the forearm Yaw part using 12mm m3 screws. Then, before adding in the wrist pitch motor holder, make sure to put the motor into the part and secure it using the m2 screws. Then, using 12mm m3 screws connect the part to the bottom of the forearm bars as the bars go over the screws. 

Fasteners: M2 5mm self tapping screws (4x), M3 12mm (8x)

---

### Step 8



Description: Now attach the wrist pitch to roll connector to the wrist pitch motor using the m3 motor screws on both sides (make sure to add the extra static horn). Then attach the wrist roll motor to the second set of servo horn connectors. Use the same m3 motor holes for this.

Fasteners: M3 6mm motor screws (18x)

---

### Step 9



Description: Press the Wrist holder part onto the wrist roll motor and secure it using M2 self-tapping screws at the top and the bottom. Then press the gripper servo into the side of the wrist holder part and secure it using M2 self-tapping screws at the top and the bottom.

Fasteners: M2 self tapping screws (8x) 

---

### Step 10



Description: Now fasten the stationary claw hand using M3 screws on the top and the bottom to keep it in place. Use 6mm at the top and 8mm at the bottom to account for the changes in thickness. Then attach both the top and the bottom non-stationary claw arms first to the servo horns and then together via m3 screws (6mm)

Fasteners: M3 6mm motor screws (9x), M3 6mm (4x), M3 8mm (2x)

---

### Step 11



Description: Now take both sub sections that were made (Bicep and Forearm) and connect them both via elbow pitch part and elbow pitch motor (Area Circled in the picture). Use m3 motor screws and make sure to add the static horn on the other side when attaching the sections.

Fasteners: M3 6mm motor screws (9x)

---

### Step 12



Description: Return to the shoulder roll motor holder and press the shoulder roll motor into the part. Then use M2 self-tapping screws to secure it in place.

Fasteners: M2 self tapping screws (4x) 

---

### Step 13





Description: Now take the arm section from the previous steps (Bicep + Forearm + Wrist) and attach it to the shoulder roll motor from the shoulder roll part using m3 motor screws. This marks the completion of one arm on one side.

Fasteners: M3 6mm motor screws (9x)

---

## Second Arm

The second arm is a mirror of the first. Print the mirrored versions of the parts in the print list, then repeat Steps 1 through 13. Servo orientation flips, so check the horn position against the CAD before tightening anything down.



---

## Stand and Mounting





Description: This stand is made of wood to keep it cheap and easy to build. First, place two pieces of wood parallel to each other on either side of the 4040, then put a piece of wood in front of the two pieces of wood in such a way that they are touching each other. Then use the self-tapping screws to connect these 3 pieces of wood together to form a T-shape around the 4040 extrusion. It should hold the extrusion tight. Then add the 6-inch piece of wood in the back and use the self-tapping screws to secure it in place, but don't tighten it too much. Just enough so that the piece stays straight up, as when tightened the parallel pieces of wood will converge and make the wood bend.

Fasteners: 20 in 2x4 wood (3x), 6 in 2x4 wood (1x), 3 in #8 self tapping wood screws (8x)

---

## Wiring

Use the wires and connect each to each other's ports in the back of the servos; make sure the wires in the daisy chain don't hinder the movements of the joint. Connect 8 motors to one of the Waveshare UART ports and another 8 connected to the other UART port to make one long daisy chain.

Both ports on the Waveshare adapter are parallel taps on the same bus, not independent channels. All 16 servos share one bus, which is why the IDs have to be unique across both arms.

Daisy chain each arm servo to servo, then run one 3-prong cable from each arm back to the adapter board. Power the board from the 12 V 10 A supply before connecting USB to the host computer.

---

Once these steps are completed, the arm will be fully assembled. You can now move on to working with software and implementing movement protocols.

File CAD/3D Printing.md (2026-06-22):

# 3D Printing Guidelines

- Use **PETG** filament for all parts
- Use **gyroid infill** pattern
- Use **3–4 wall loops** on every part
- 20-25% infill for all parts, higher for critical movement components such as parts connected to motors and joints.

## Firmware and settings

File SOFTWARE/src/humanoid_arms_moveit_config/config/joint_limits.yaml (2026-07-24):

# joint_limits.yaml allows the dynamics properties specified in the URDF to be overwritten or augmented as needed

# For beginners, we downscale velocity and acceleration limits.
# You can always specify higher scaling factors (<= 1.0) in your motion requests.  # Increase the values below to 1.0 to always move at maximum speed.
default_velocity_scaling_factor: 0.1
default_acceleration_scaling_factor: 0.1

# Specific joint properties can be changed with the keys [max_position, min_position, max_velocity, max_acceleration]
# Joint limits can be turned off with [has_velocity_limits, has_acceleration_limits]
joint_limits:
  leftarmyaw:
    has_velocity_limits: true
    max_velocity: 4.7599999999999998
    has_acceleration_limits: true
    max_acceleration: 10.0
  leftelbowpitch:
    has_velocity_limits: true
    max_velocity: 4.7599999999999998
    has_acceleration_limits: true
    max_acceleration: 10.0
  leftforearmyaw:
    has_velocity_limits: true
    max_velocity: 4.7599999999999998
    has_acceleration_limits: true
    max_acceleration: 10.0
  leftgripper:
    has_velocity_limits: true
    max_velocity: 4.7599999999999998
    has_acceleration_limits: true
    max_acceleration: 10.0
  leftshoulderpitch:
    has_velocity_limits: true
    max_velocity: 4.7599999999999998
    has_acceleration_limits: true
    max_acceleration: 10.0
  leftshoulderroll:
    has_velocity_limits: true
    max_velocity: 4.7599999999999998
    has_acceleration_limits: true
    max_acceleration: 10.0
  leftwristpitch:
    has_velocity_limits: true
    max_velocity: 4.7599999999999998
    has_acceleration_limits: true
    max_acceleration: 10.0
  leftwristroll:
    has_velocity_limits: true
    max_velocity: 4.7599999999999998
    has_acceleration_limits: true
    max_acceleration: 10.0
  rightarmyaw:
    has_velocity_limits: true
    max_velocity: 4.7599999999999998
    has_acceleration_limits: true
    max_acceleration: 10.0
  rightelbowpitch:
    has_velocity_limits: true
    max_velocity: 4.7599999999999998
    has_acceleration_limits: true
    max_acceleration: 10.0
  rightforearmyaw:
    has_velocity_limits: true
    max_velocity: 4.7599999999999998
    has_acceleration_limits: true
    max_acceleration: 10.0
  rightgripper:
    has_velocity_limits: true
    max_velocity: 4.7599999999999998
    has_acceleration_limits: true
    max_acceleration: 10.0
  rightshoulderpitch:
    has_velocity_limits: true
    max_velocity: 4.7599999999999998
    has_acceleration_limits: true
    max_acceleration: 10.0
  rightshoulderroll:
    has_velocity_limits: true
    max_velocity: 4.7599999999999998
    has_acceleration_limits: true
    max_acceleration: 10.0
  rightwristpitch:
    has_velocity_limits: true
    max_velocity: 4.7599999999999998
    has_acceleration_limits: true
    max_acceleration: 10.0
  rightwristroll:
    has_velocity_limits: true
    max_velocity: 4.7599999999999998
    has_acceleration_limits: true
    max_acceleration: 10.0

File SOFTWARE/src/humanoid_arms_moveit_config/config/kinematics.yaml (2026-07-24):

left_arm:
  kinematics_solver: pick_ik/PickIkPlugin
  kinematics_solver_timeout: 0.2
  kinematics_solver_attempts: 5
  mode: global
  position_scale: 1.0
  rotation_scale: 0.1
  position_threshold: 0.005
  orientation_threshold: 0.5
  cost_threshold: 0.01
  minimal_displacement_weight: 0.001
  gd_step_size: 0.0001

right_arm:
  kinematics_solver: pick_ik/PickIkPlugin
  kinematics_solver_timeout: 0.2
  kinematics_solver_attempts: 5
  mode: global
  position_scale: 1.0
  rotation_scale: 0.1
  position_threshold: 0.005
  orientation_threshold: 0.5
  cost_threshold: 0.01
  minimal_displacement_weight: 0.001
  gd_step_size: 0.0001

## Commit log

2026-06-19 Rename BOM - Sheet1.csv to BOM/csv file of BOM
2026-06-19 Rename BOM.md to BOM/BOM LINK.md
2026-06-22 Create 3D Printing.md
2026-07-24 Add humanoid arm control & teleop software
    [Composant3_3.stl, Composant3_6.stl, Composant3_7.stl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]
2026-07-24 Replace image for second arm in INSTRUCTIONS.md
    Updated image for the second arm section in instructions.
2026-07-24 Insert image of finished arm assembly
    Added an image of the finished arm assembly.
2026-08-07 Add Bill of Materials section to README
    Added detailed Bill of Materials (BOM) with parts, quantities, prices, and notes.
